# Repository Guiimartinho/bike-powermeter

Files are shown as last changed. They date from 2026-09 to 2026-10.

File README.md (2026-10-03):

<div align="center">

# Bike Power Meter

**Medidor de potência para bicicleta, aberto do extensômetro ao pod: torque por ponte de classe transdutor colada no braço do pedivela, cadência por acelerômetro, potência por BLE e ANT+. Par do [GNSS Bike Computer](https://github.com/Guiimartinho/gnss-bike-computer).**













</div>

Um módulo colado na face interna do braço esquerdo do pedivela. A ponte de extensômetros mede a **deformação do próprio braço**, que é o elemento elástico; o conversor lê a ponte em 24 bits, o acelerômetro dá o ângulo e a cadência, e o rádio publica potência, cadência e equilíbrio como qualquer medidor comercial — em **BLE Cycling Power** e **ANT+ Bicycle Power**, para o ciclocomputador do projeto ou para qualquer aplicativo.

O firmware é **obra original** em C puro sobre Zephyr, não um port. A placa, o pod e todos os desenhos são **gerados por programa** a partir dos documentos de [`hardware_powermeter/`](hardware_powermeter/README.md), pela mesma ideia do ciclocomputador: um gerador, um dry run, e nenhum número que não venha de uma ficha ou de uma medida.

> [!WARNING]
> **Nada foi fabricado, impresso, soldado nem colado, e o firmware nunca rodou.** Não existe placa física, nenhum extensômetro foi colado num pedivela, nenhum componente passou por bancada e nenhuma linha de código foi vista funcionando: tudo o que está escrito abaixo foi verificado no PC. As medidas do braço do pedivela são **lugares reservados** — ninguém mediu o braço. O estado de cada área está em [docs/07-status.md](docs/07-status.md).

## Índice

- [Visão geral](#visão-geral)
- [O aparelho](#o-aparelho)
- [Como a potência sai da deformação](#como-a-potência-sai-da-deformação)
- [Componentes](#componentes)
- [Funcionalidades](#funcionalidades)
- [Início rápido](#início-rápido)
- [Estrutura](#estrutura)
- [Documentação](#documentação)
- [Estado e próximos passos](#estado-e-próximos-passos)
- [Créditos e licença](#créditos-e-licença)

## Visão geral

```mermaid
flowchart LR
    subgraph POD["Pod colado no braço esquerdo"]
        G["Ponte S5229<br/>5 kΩ, uma peça"] -->|"2 mV"| A["ADS1220<br/>24 bits, ganho 128"]
        I["BMA400<br/>ângulo e cadência"] --> M["nRF54L15<br/>HOLYIOT-26001-A"]
        T["TMP117<br/>±0,1 °C"] --> M
        A --> M
        P["nPM1100 + célula LiPo"] --> M
        C["conector magnético<br/>carga, serial, SWD"] --> P
    end
    M -- "BLE Cycling Power" --> CC["ciclocomputador<br/>ou qualquer app"]
    M -- "ANT+ Bicycle Power" --> CC
```

## O aparelho

<div align="center">

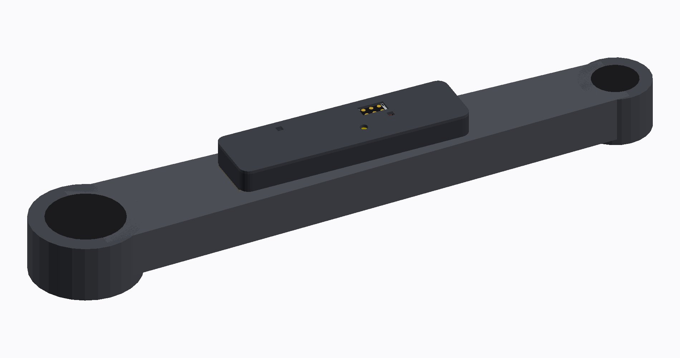
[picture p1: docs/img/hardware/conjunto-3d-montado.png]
O pod colado no braço do pedivela, visto em ângulo: a caixa preta no meio do braço, com a janela do conector magnético na tampa


*O pod no braço do pedivela. O braço é um lugar reservado, desenhado da classe (170 mm entre eixos) até o do dono ser medido; o pod, a placa e a ponte são a geometria real do projeto.*

</div>

### O produto, peça por peça

| | |
|---|---|
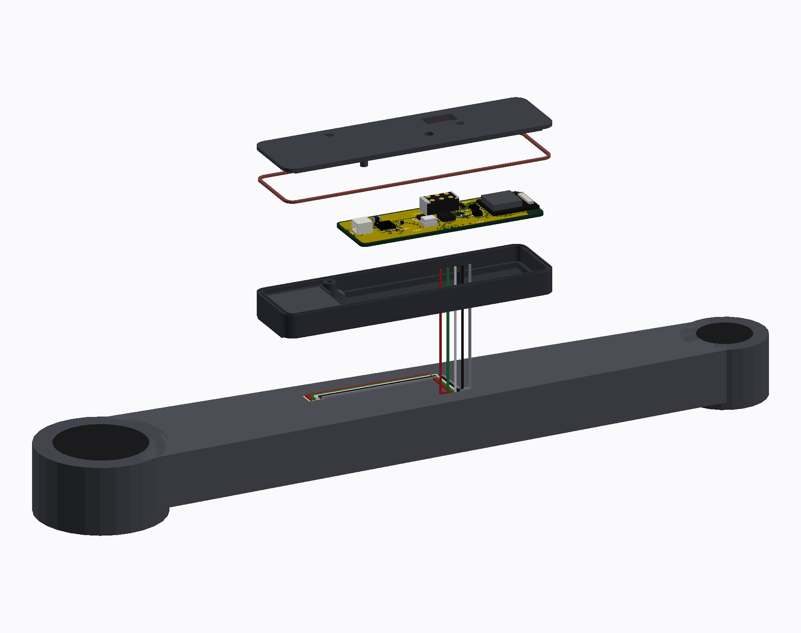
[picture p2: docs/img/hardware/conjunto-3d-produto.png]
O conjunto em vista explodida de produto: tampa, anel O, placa, célula e concha, um sobre o outro
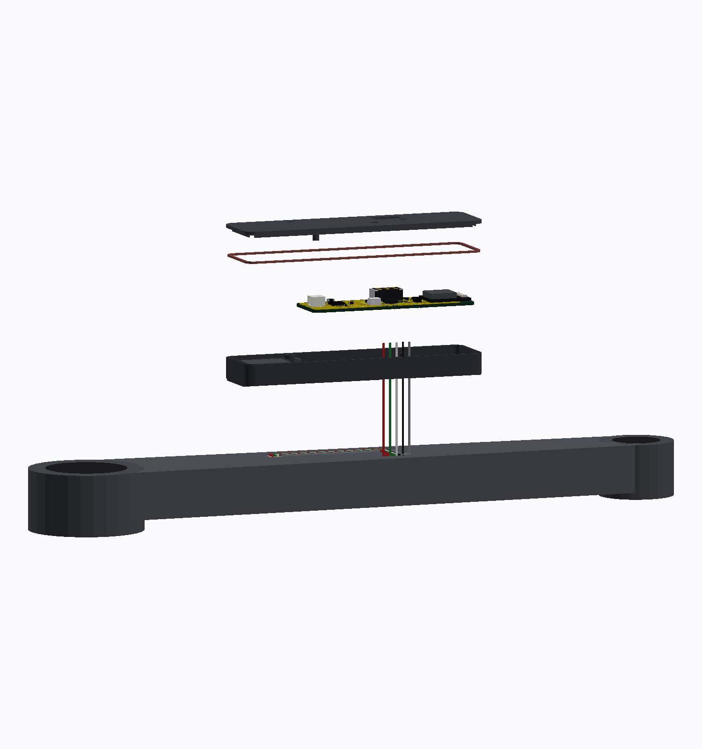
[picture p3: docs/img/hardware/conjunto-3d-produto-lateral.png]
A mesma pilha vista de lado, mostrando as alturas de cada camada
|  |  |
| *A pilha inteira: tampa, anel O, placa, célula e concha* | *De lado: 7,7 mm do fundo ao topo da tampa* |
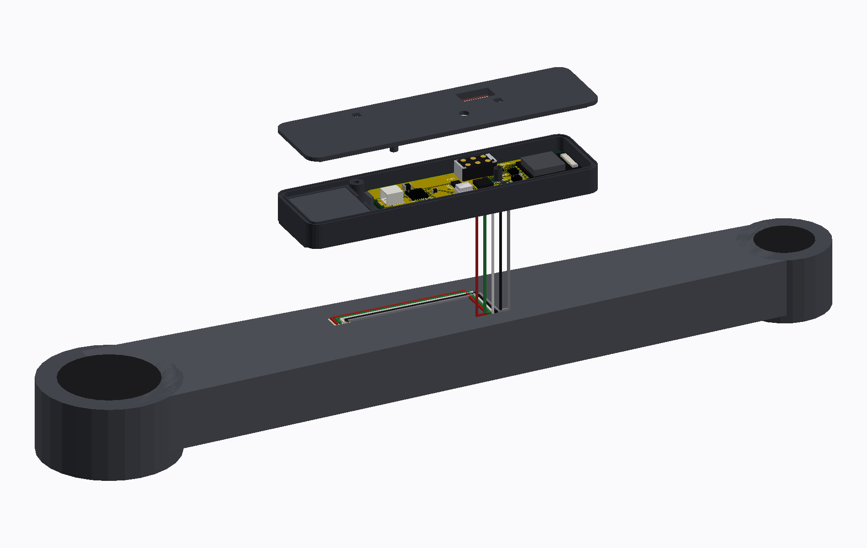
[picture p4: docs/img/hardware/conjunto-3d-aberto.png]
O conjunto em vista explodida: a tampa, o pod com a placa dentro, os cinco fios descendo e a ponte colada no braço
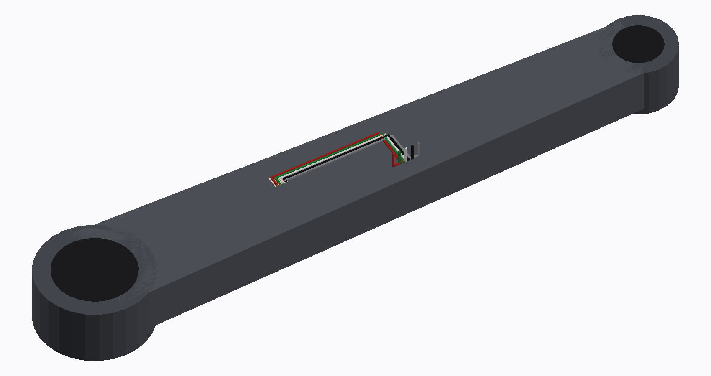
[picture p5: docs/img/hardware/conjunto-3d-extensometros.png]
Os extensômetros no braço, sob o pod
|  |  |
| *Aberto: a ponte fica no **braço**, não no pod, e cinco fios sobem por um rasgo no fundo* | *A ponte S5229 colada na face interna do braço* |

### O pod

| | |
|---|---|
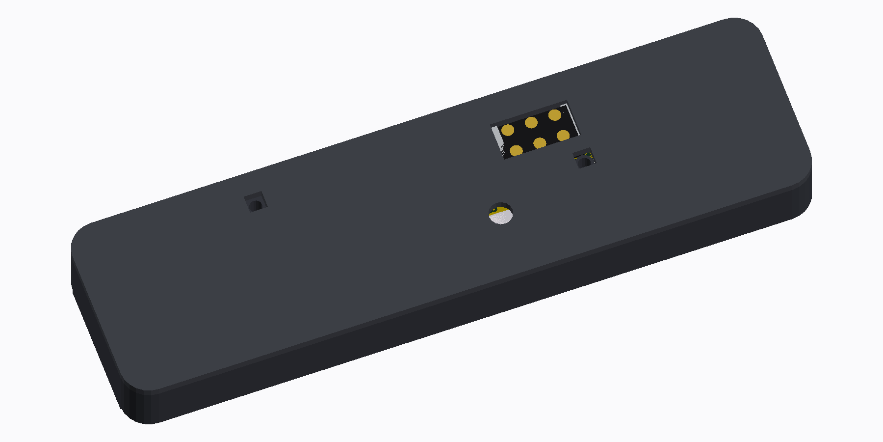
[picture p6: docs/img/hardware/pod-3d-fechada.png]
O pod fechado, visto em ângulo
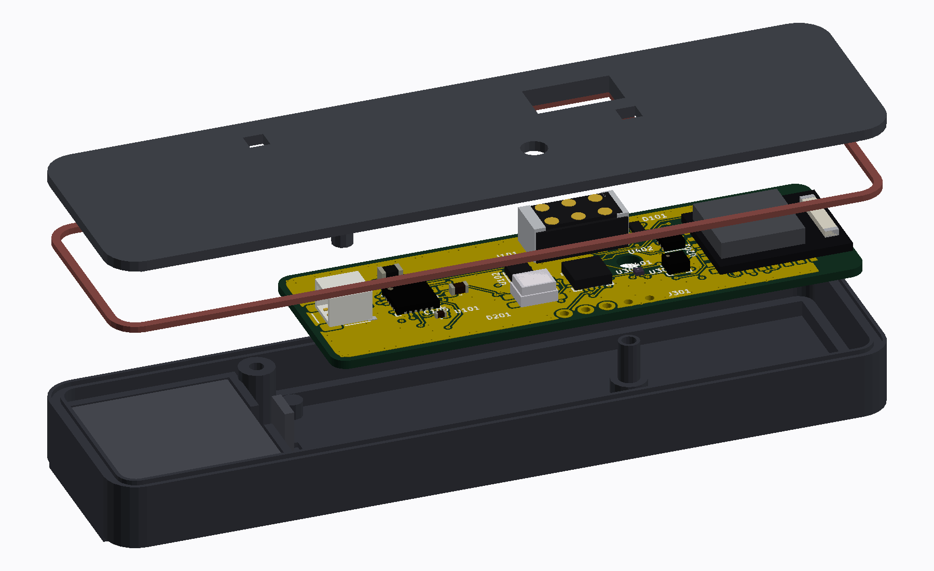
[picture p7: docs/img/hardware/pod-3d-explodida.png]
O pod em vista explodida: concha, célula, placa, anel O e tampa
|  |  |
| *Fechado: 73,5 × 20,0 × 7,7 mm, 14,3 g estimados* | *Explodido: concha, célula, placa, anel O e tampa* |
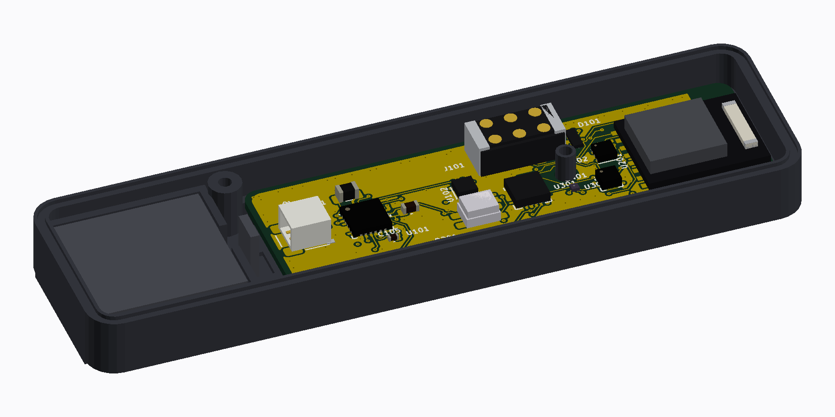
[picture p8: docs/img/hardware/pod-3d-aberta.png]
A concha aberta com a placa dentro
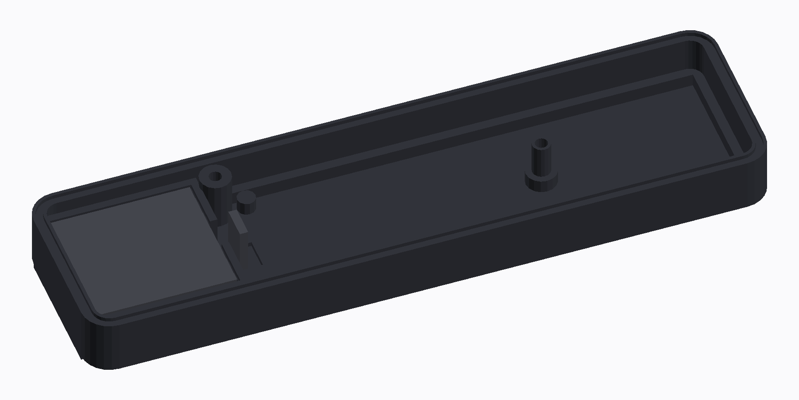
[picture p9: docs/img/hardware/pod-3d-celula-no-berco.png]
A célula no berço da concha, antes da placa
|  |  |
| *Aberto, com a placa assentada* | *A célula no berço, no passo em que ela entra* |
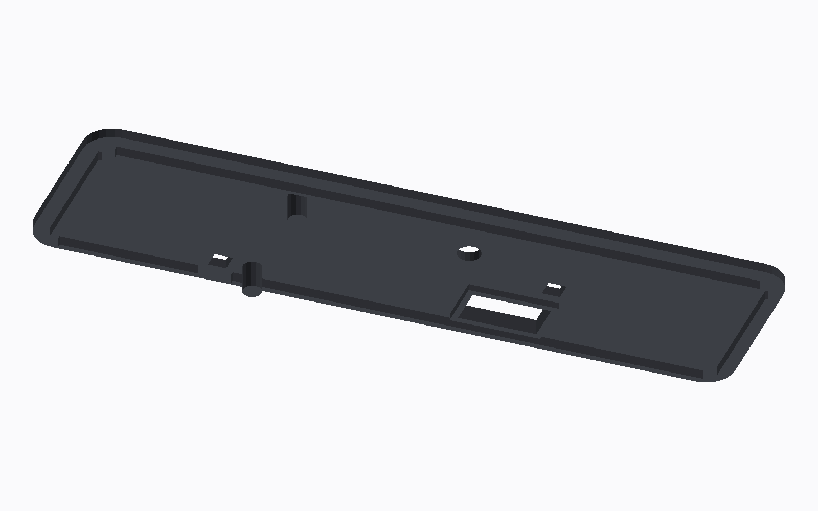
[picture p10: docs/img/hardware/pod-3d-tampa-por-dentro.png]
A tampa vista por dentro: o sulco do anel O, os dedos que prendem a placa e o ressalto que comprime a junta da porta
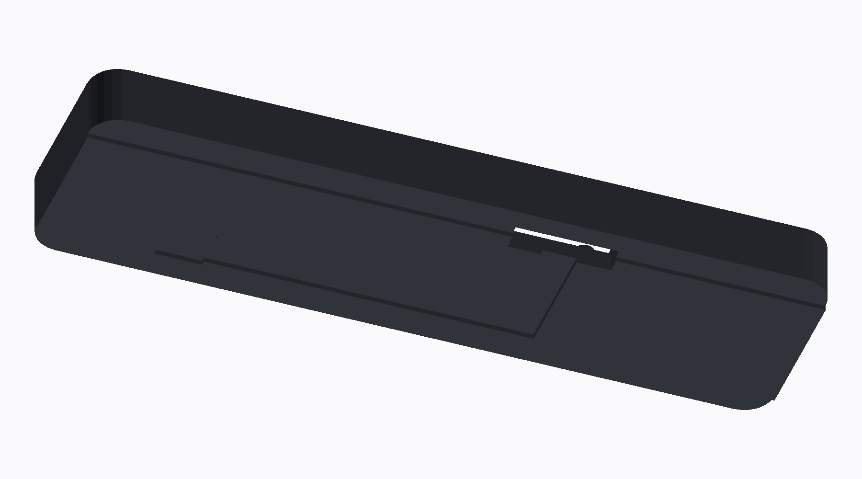
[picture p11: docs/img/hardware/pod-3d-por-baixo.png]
A concha vista por baixo: a base de colagem, o relevo, o rasgo dos fios, o bolso do extensômetro e a canaleta do feixe
|  |  |
| *A tampa por dentro: sulco do anel O, dedos da placa e o ressalto que comprime a junta da porta* | *Por baixo: a base de colagem de 14 mm, o relevo de 0,5, o rasgo dos fios, o bolso do extensômetro e a canaleta do feixe* |

### A placa

| | |
|---|---|
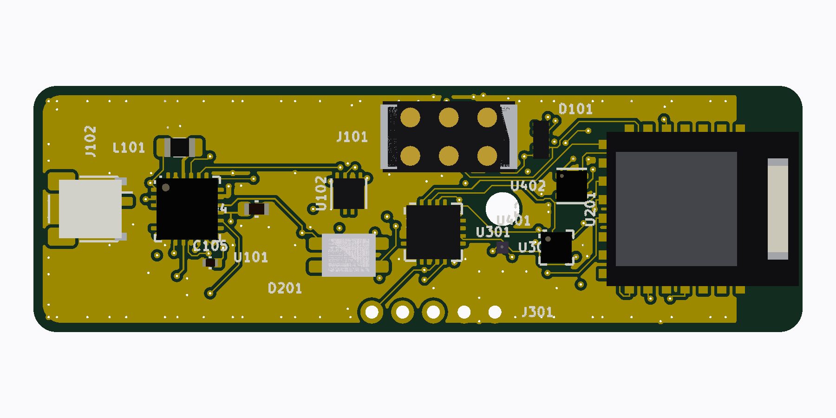
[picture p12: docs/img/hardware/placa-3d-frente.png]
A placa vista pela frente: o módulo de rádio à direita, o conector magnético na borda de cima, o conversor no meio e o conector da célula na ponta esquerda
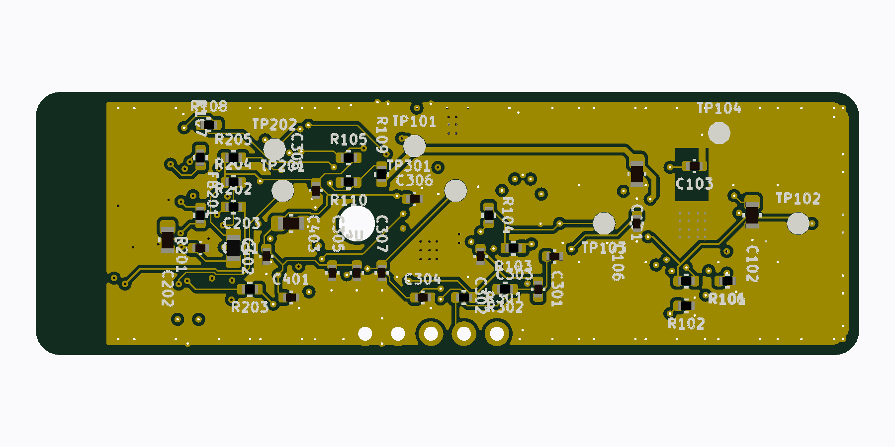
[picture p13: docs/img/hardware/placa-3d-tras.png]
A placa pelo verso: os pontos de teste e os passivos que não precisam ser alcançados
|  |  |
| *A placa, 50 × 16 mm em 4 camadas, 58 peças* | *O verso: pads de teste e o que não precisa ser alcançado, sobre o fundo rebaixado do pod* |
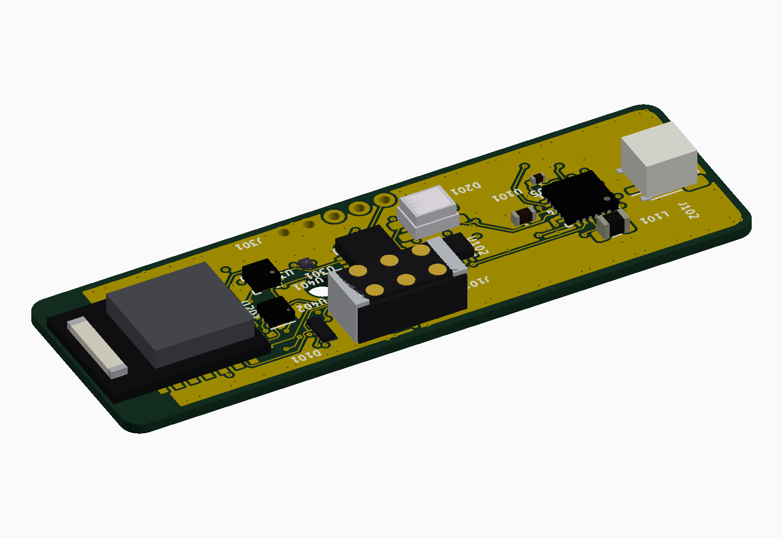
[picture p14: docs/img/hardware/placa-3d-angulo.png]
A placa vista em ângulo, com os corpos 3D de cada peça
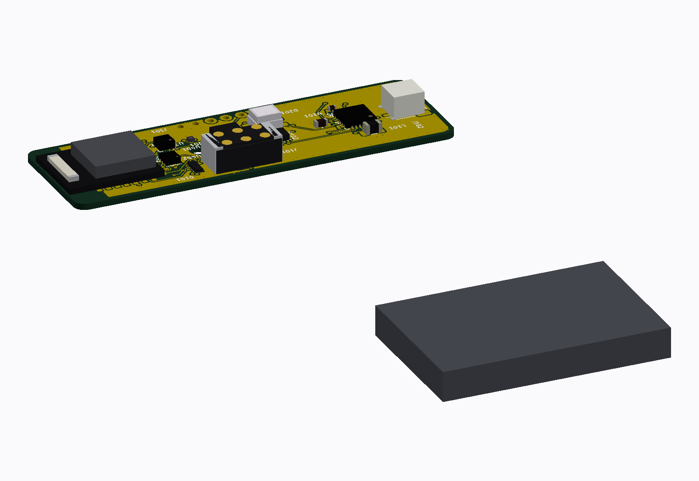
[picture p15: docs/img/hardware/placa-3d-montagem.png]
A placa com os nomes de cada peça, para a montagem
|  |  |
| *Em ângulo, com o corpo real de cada peça* | *O mapa de montagem, peça a peça* |

O envelope de referência veio de **fotogrametria** sobre as fotos de imprensa de um medidor da classe, porque nenhum fabricante publica as medidas: 37 a 39 mm de comprimento, 18 a 22 de largura e 9 a 13 de altura, com a escala aferida por dois caminhos independentes ([docs/01](docs/01-visao-geral.md)). É contra esse número que o pod é medido.

## Como a potência sai da deformação

O que quase todo texto sobre medidores esconde: **o sensor não mede força, mede o quanto o braço entorta.**

```mermaid
flowchart LR
    F["força no pedal<br/>~500 N"] --> D["o braço flexiona<br/>~571 µε na borda"]
    D --> V["a ponte desequilibra<br/>~2,28 mV"]
    V --> N["ADS1220, ganho 128<br/>24 bits ratiométrico"]
    N --> TQ["torque<br/>zero, inclinação, temperatura"]
    TQ --> PW["potência = torque × ω"]
    ANG["BMA400<br/>ângulo e ω"] --> PW
```

Duas coisas foram **medidas e corrigidas** aqui, e as duas mudam o aparelho:

- **o padrão de extensômetro especificado estava errado.** A lista pedia padrão de cisalhamento a 45°, que é padrão de torquímetro de eixo; o braço do pedivela é uma viga em balanço. Na mesma seção, a grade a 45° lê 52 µε e a grade axial na borda lê 459 µε: **8,9 vezes mais** ([docs/06](docs/06-medicao-e-calibracao.md));
- **o braço Shimano é oco.** Com parede de 3 mm o momento de inércia cai de 9.333 para 7.504 mm⁴ e a deformação sobe de 459 para **571 µε**, 24 % a mais.

A ponte é **uma peça só**, não quatro colagens: o padrão S5229 do databook de classe transdutor, `N2K-13-S5229A-50C/DG/E3`, 5 kΩ ±5 %, matriz de 4,0 × 3,7 mm, ponte de Poisson já balanceada de fábrica. O código `13` é a autocompensação para alumínio; **sem ele escrito no pedido o fabricante embarca o `06`, que é o de aço**.

## Componentes

| Bloco | Peça | Por quê |
|---|---|---|
| Ponte | Micro-Measurements `N2K-13-S5229A-50C/DG/E3` | ponte completa numa colagem só, 5 kΩ (0,6 mA em vez de 3,0), balanceada de fábrica, autocompensada para alumínio |
| Conversor | TI ADS1220 | 0,26 µV RMS com ganho 128, 585 µA medindo, referência **ratiométrica** (a excitação é a referência, então a tensão da célula sai da conta) |
| Cadência e ângulo | Bosch BMA400 | 850 nA a 25 Hz; driver próprio, porque o `bosch,bma4xx` da árvore usa o mapa do BMA422 |
| Temperatura | TI TMP117 | ±0,1 °C para o ajuste do zero e da inclinação |
| MCU e rádio | **HOLYIOT-26001-A** (nRF54L15), antena cerâmica | 10,0 × 12,5 mm contra 16,5 × 12,0 do ME54BS13: o módulo era **26 % da área da placa**, mais que as 37 peças pequenas somadas, e é a única alavanca de tamanho que move alguma coisa. Custa o USB, que este SoC não tem ([09](hardware_powermeter/09-modulo-de-radio.md)) |
| Carga e 3,0 V | Nordic nPM1100 | carregador e buck numa peça, 800 nA |
| Excitação | TI TPS22916 | desliga a ponte entre amostras; é ela que faz os 5 kΩ valerem a pena |
| Bateria | LiPo de bolsa classe **`401123`** (4,0 × 11 × 23 mm, ≥ 78 mAh, dois fios, proteção integrada) | a 0,68 mA — ponte de 5 kΩ com o conversor em duty-cycle — são **114 h**, contra as 50 h do requisito. A premissa anterior, de 2,5 mm de espessura, não existe: naquele volume a célula vale ~49 mAh. Nenhuma loja foi alcançada: o envelope é **requisito de compra** |
| Conector | magnético de 6 contatos, **desenhado aqui** | carga, serial e SWD num cabo só, sem tampa de borracha para perder. Contatos chatos de ouro no aparelho e molas no cabo, para o pod poder ser vedado ([06](hardware_powermeter/06-conectores-e-pontos-de-teste.md#j101--conector-magnético)) |

Lista completa, com a ficha e o código de compra de cada peça: [`hardware_powermeter/01-lista-de-componentes.md`](hardware_powermeter/01-lista-de-componentes.md).

## Funcionalidades

| Funcionalidade | Estado |
|---|---|
| Torque por ponte, com zero, inclinação e ajuste de temperatura | modelo escrito e testado no PC (18 casos, 50 de 50 linhas) |
| Ângulo e cadência pelos cruzamentos de zero do eixo tangencial | modelo escrito e testado (18 casos, 113 de 113 linhas) |
| Potência, equilíbrio e eficiência por volta | modelo escrito e testado (12 casos, 80 de 80 linhas) |
| Calibração: zero, inclinação por mínimos quadrados, massa conhecida | modelo escrito e testado (18 casos, 135 de 135 linhas) |
| BLE Cycling Power (Measurement, Feature, Control Point, Vector) | compila; os bytes vêm do modelo testado; nunca visto por um cliente |
| Serviço de configuração por BLE, com **escrita cifrada obrigatória** | compila; nunca emparelhado |
| ANT+ Bicycle Power (páginas 1, 16, 18, 80, 81) | compila com `ANT=1`; nenhum canal aberto de verdade |
| Atualização por BLE (mcumgr + MCUboot) e recuperação serial pela **UART** do conector magnético | compila; recusa pedalando ou com bateria fraca |
| Placa e pod gerados por programa, com dry run | placa colocada; pod fecha **16 de 16** regras, com vedação por anel O, parafusos, retenção e dreno |

## Início rápido

**Pré-requisitos** (Windows): nRF Connect SDK v3.3.0 em `C:\ncs` com o toolchain `936afb6332`, SEGGER J-Link e um nRF54LM20 DK. Para o ANT, o add-on `sdk-ant` em `C:\ncs\sdk-ant`, depois de aceitar o acordo ANT+. Para os testes de host, MinGW-w64 GCC, CMake e Ninja. Para o CAD, KiCad 8 em `D:\KiCAD`. Detalhes em [docs/03-ambiente-build.md](docs/03-ambiente-build.md).

```sh
# Git Bash, na raiz do repositório
bash tools/fw/fw.sh build            # compila para o nRF54LM20 DK (sysbuild + MCUboot)
BOARD=pmboard/nrf54l15/cpuapp BUILD_DIR=zephyr_app/build_custom bash tools/fw/fw.sh build
ANT=1 BUILD_DIR=zephyr_app/build_ant bash tools/fw/fw.sh build   # com a pilha ANT+
bash tools/fw/host_tests.sh          # 9 conjuntos, 134 casos
bash tools/fw/host_tests.sh coverage # e falha abaixo de 95 % em qualquer módulo
python tools/fw/board_check.py       # confere o devicetree contra o silício, docs/02 e o esquemático
python tools/docs/mermaid_check.py   # valida os diagramas da documentação
python tools/verificar_tudo.py       # a verificação inteira, três vezes
```

A cadeia de CAD, com o intérprete certo de cada etapa (o `fill_zones.py` **só** roda com o Python do KiCad), está em [`hardware_powermeter/cad/README.md`](hardware_powermeter/cad/README.md#a-cadeia).

O CI está **desligado**: a verificação é local.

## Estrutura

```mermaid
flowchart TB
    ROOT["bike_powermeter/"]
    ROOT --> ZA["zephyr_app/<br/>src (app · svc · model · rf) · include<br/>modules/pm_drivers (ADS1220, BMA400)<br/>boards · tests/host"]
    ROOT --> HW["hardware_powermeter/<br/>01 a 10 · cad (KiCad e geradores)<br/>esquematico · placa · pod (gerador, dry run, STL)<br/>datasheets (fora do git)"]
    ROOT --> DOCS["docs/<br/>01 a 07 · img/hardware (15 vistas)"]
    ROOT --> TOOLS["tools/<br/>fw · docs · verificar_tudo.py"]
    ROOT --> AI["CLAUDE.md · AGENTS.md · .claude/skills/"]
```

## Documentação

| Documento | Assunto |
|---|---|
| [01 · Visão geral](docs/01-visao-geral.md) | o que é, o envelope da classe por fotogrametria, as fases |
| [02 · Hardware](docs/02-hardware.md) | blocos da placa, pinos do módulo, orçamento de consumo, pod |
| [03 · Ambiente e build](docs/03-ambiente-build.md) | NCS v3.3.0, os três alvos, scripts, gravação |
| [04 · Arquitetura do firmware](docs/04-arquitetura-firmware.md) | os seis serviços, threads, pilhas, máquinas de estado |
| [05 · Protocolos](docs/05-protocolos.md) | BLE Cycling Power, ANT+ Bicycle Power, serviço de configuração com os UUID |
| [06 · Medição e calibração](docs/06-medicao-e-calibracao.md) | da deformação ao torque, flexão × cisalhamento, zero, inclinação, temperatura, saúde |
| [07 · Status](docs/07-status.md) | o que existe, o que foi verificado e como, o que falta |
| [Hardware](hardware_powermeter/README.md) | o esquemático, a placa, o pod, os dry runs e o que falta antes de fabricar |
| [CAD](hardware_powermeter/cad/README.md) | os geradores, as regras e as armadilhas medidas |
| [Pod](hardware_powermeter/pod/README.md) | o gerador do invólucro, as 32 regras do dry run e o que é decisão do desenho |
| [Módulo de rádio](hardware_powermeter/09-modulo-de-radio.md) | o HOLYIOT-26001-A: por que entrou, o que o nRF54L15 muda, pinagem, mecânica, a antena |
| [A classe medida](hardware_powermeter/12-comparacao-com-a-classe.md) | o 4iiii Precision 3+ e o U2e V4 contra o nosso, e o que custaria chegar ao alvo de envelope |
| [CHANGELOG](CHANGELOG.md) | histórico de mudanças |

## Estado e próximos passos

- **Feito em 2026-09-27:** a documentação de requisitos, arquitetura, protocolos e método de medição com as referências; a lista de componentes fechada por ficha; os nove módulos do modelo escritos e testados no PC (134 casos, 100 % das linhas, doze mutações mortas); o firmware embarcado inteiro compilando com **zero avisos** nos três alvos; o esquemático, a placa e o pod gerados por programa com os dois dry runs.
- **Feito em 2026-09-28:** a ponte fechada numa peça só (S5229 de 5 kΩ) com a designação de compra dos braços do dono; a correção do padrão de extensômetro (flexão, não cisalhamento: 8,9 vezes mais sinal); o roteador passou a ser julgado pelo **DRC do KiCad** em vez da própria contabilidade; três defeitos mecânicos do pod medidos e corrigidos, e o dry run fechou **12 de 12**.
- **Falta antes de fabricar:** fechar o roteamento, medir o pedivela do dono (quatro números), escolher a célula, fechar o conector magnético e conferir o empilhamento com o fabricante. A lista está em [`hardware_powermeter/README.md`](hardware_powermeter/README.md#antes-de-mandar-fabricar).
- **Depois:** bancada com massas de 5 a 20 kg contra o braço instrumentado, prova de estrada contra um medidor de referência até ±2 %, e a fase 2 no eixo de pedal.

## Créditos e licença

Projeto de Luiz Guilherme Ito. As referências técnicas — notas de aplicação dos fabricantes, databooks de extensometria, normas e artigos — estão citadas nos documentos que as usam, principalmente em [`docs/06-medicao-e-calibracao.md`](docs/06-medicao-e-calibracao.md) e [`hardware_powermeter/01-lista-de-componentes.md`](hardware_powermeter/01-lista-de-componentes.md).

Licença **CC BY-NC 4.0** ([`LICENSE`](LICENSE)), a mesma do GNSS Bike Computer: copiar, estudar, modificar e redistribuir com atribuição, **sem uso comercial**. Não é licença aprovada pela Open Source Initiative, que não admite restrição de uso, e foi escolhida por isso. O firmware deste projeto é obra original, não um port.

O material do ANT+ — perfis de dispositivo, código sob a ANT+ Shared Source License, chave de rede — **nunca entra neste repositório**: o ANT+ Adopter Agreement proíbe redistribuir. O que existe aqui é código próprio chamando a API do add-on. As fichas dos fabricantes ficam fora do git.

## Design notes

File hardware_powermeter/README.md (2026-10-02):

# Hardware do medidor de potência

O aparelho inteiro em CAD: o esquemático, a placa de quatro camadas, o pod
impresso em volta dela e as medidas que cada um tem de passar. Tudo é
**gerado por programa** a partir dos documentos desta pasta, pela mesma
ideia do ciclocomputador: um gerador, um dry run, e nenhum número que não
venha de uma ficha ou de uma medida.

> [!WARNING]
> **Nada foi fabricado, impresso, soldado nem colado.** Não existe gerber
> enviado, não existe placa física, nenhuma peça passou por bancada e
> nenhum extensômetro foi colado num pedivela. O que existe é o projeto em
> KiCad, os STL do pod e os dry runs que os medem. As medidas do braço do
> pedivela são **lugares reservados**: ninguém mediu o braço do dono.

## Índice

- [O que existe](#o-que-existe)
- [A cadeia](#a-cadeia)
- [Os documentos](#os-documentos)
- [Os dry runs](#os-dry-runs)
- [Antes de mandar fabricar](#antes-de-mandar-fabricar)

## O que existe

| Parte | Estado |
|---|---|
| Esquemático | 4 folhas, 58 peças, 43 nós, gerado e conferido nó a nó contra `nets.py` pelo `check_sch.py` |
| Placa | **50 × 16 mm**, 4 camadas, 58 peças mais um furo de fixação M1,6, 43 redes; **roteada por inteiro** — 838 trilhas, 221 vias, 0 erros de DRC e 0 ligações em aberto |
| Pod | **73,5 × 20,0 × 7,7 mm**, 14,5 g estimados, com a célula **ao lado** da placa, vedado por anel O e por uma junta no ombro do conector, fechado por dois parafusos M1,6, dois STL (concha e tampa) |
| Ponte | S5229 de 5 kΩ numa peça só, `N2K-13-S5229A-50C/DG/E3`, colada no braço |

## A cadeia

```mermaid
flowchart LR
    SCH["make_sch.py"] --> CSCH["check_sch.py"]
    CSCH --> PDFS["esquematico/pmeter-esquematico.pdf"]
    DXF["make_dxf.py"] --> CDXF["check_dxf.py"]
    CDXF --> PCB["make_pcb.py"]
    PCB --> ROUTE["route.py + route_neg.py"]
    ROUTE --> FILL["fill_zones.py"]
    FILL --> DRC["kicad-cli pcb drc"]
    DRC --> REP["reparar.py"]
    REP --> DRY["dry_run_pcb.py"]
    DRY --> V3D["make_3d.py · make_2d.py · montagem.py"]
    V3D --> POD["pod/dry_run_pod.py · pod/make_pod.py"]
    POD --> CONJ["pod/make_conjunto.py"]
```

Os comandos, um a um, com o intérprete certo de cada etapa, estão em
[`cad/README.md`](cad/README.md#a-cadeia). Duas armadilhas que custam caro:
o `fill_zones.py` **só** roda com o Python do KiCad, e o `check_pcb.py`
regera a placa se você esquecer o `--como-esta`.

## Os documentos

| Documento | Assunto |
|---|---|
| [01 · Lista de componentes](01-lista-de-componentes.md) | cada peça com o número da ficha, incluindo a ponte S5229 e as armadilhas de compra |
| [02 · Esquemático](02-esquematico.md) | as quatro folhas, bloco a bloco |
| [03 · Netlist](03-netlist.md) | os 43 nós, pino a pino, e os pinos deixados abertos de propósito |
| [04 · Placa](04-placa.md) | contorno, camadas, posicionamento, zonas proibidas, land pattern do módulo, roteamento |
| [05 · Materiais](05-materiais.md) | a lista de montagem com footprint e código de compra |
| [06 · Conectores e pontos de teste](06-conectores-e-pontos-de-teste.md) | o conector magnético, os furos da ponte, os furos da célula, o Tag-Connect |
| [07 · Pod](07-pod.md) | o invólucro: envelope, pilha de alturas, o que segura cada peça, vedação, massa |
| [08 · Dry run de 2026-09-27](08-dry-run-2026-09-27.md) | a primeira medida completa da placa e do pod |
| [09 · Módulo de rádio](09-modulo-de-radio.md) | o HOLYIOT-26001-A: por que ele entrou, o que o nRF54L15 muda, pinagem, mecânica, a antena |
| [10 · Dry run de 2026-09-28](10-dry-run-2026-09-28.md) | a medida completa depois da troca do módulo, da célula real e da vedação |
| [11 · Revisão de 2026-10-01](pod/11-revisao-2026-10-01.md) | dez revisores sobre o pod: sete bloqueantes, e por que o dry run não os via |
| [12 · A classe medida](12-comparacao-com-a-classe.md) | o 4iiii Precision 3+ e o U2e V4 contra o nosso, pelo que publicam; o que custaria chegar ao alvo de envelope; Apple Find My e Samsung Find |
| [CAD](cad/README.md) | os geradores, o que muda em relação ao ciclocomputador, as regras e as armadilhas |

## Os dry runs

Duas ferramentas, e as duas **falham dizendo que não puderam medir** quando
não acham o que medir — foi assim que se descobriu que a `ME2` do
ciclocomputador passou dias sem sombra nenhuma para medir.

| Ferramenta | O que mede |
|---|---|
| [`cad/dry_run_pcb.py`](cad/dry_run_pcb.py) | as regras que as fichas dos componentes e a IPC-2221B impõem à placa: isolamento da antena, laço de chaveamento, desacoplamento junto do pino, orientação do acelerômetro, corpos 3D contra o footprint |
| [`pod/dry_run_pod.py`](pod/dry_run_pod.py) | o pod contra a placa real: a placa na cavidade, o teto da tampa, a janela do conector, o ar sob cada peça do verso, a célula, o rasgo dos fios, os pilares, o envelope e a massa |

O dry run do pod lê a placa colocada, então roda **depois** do `make_pcb.py`;
o `make_conjunto.py`, que desenha o pod no braço do pedivela com a ponte
colada, roda depois dos dois.

## Antes de mandar fabricar

Nada disto foi feito, e nenhum arquivo de fabricação deve sair antes:

1. **Fechar o roteamento.** O número atual está em
   [04](04-placa.md#roteamento) e a placa **não é fabricável** enquanto
   houver ligação sem cobre.
2. **Medir o pedivela do dono** (Shimano 105 e Ultegra): largura da face
   interna, folga até o quadro, raio da concordância e distância do eixo ao
   pod. São quatro números e hoje são lugares reservados
   ([07](07-pod.md#lugares-reservados)).
3. **Escolher a célula** dentro do envelope de 23 × 13 × 2,5 mm e conferir a
   capacidade contra as 50 h de [`docs/02`](../docs/02-hardware.md#orçamento-de-consumo).
4. **Fechar o conector magnético**: a peça de hoje é genérica
   (`confirmed=False` em `cad/parts.py`), e trocá-la troca o footprint, a
   altura e a janela da tampa.
5. **Pedir a ponte com o código de autocompensação escrito**: sem ele o
   fabricante embarca o `06`, que é o de aço, e o braço do dono é de
   alumínio ([01](01-lista-de-componentes.md)).
6. **Conferir o empilhamento com o fabricante**: as quatro camadas aqui são
   assimétricas e a impedância do par USB foi calculada para 0,10 mm de
   dielétrico sob a `F.Cu`.

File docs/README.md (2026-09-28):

# Documentação

| Documento | Assunto |
|---|---|
| [01-visao-geral.md](01-visao-geral.md) | o que é o medidor, decisão de arquitetura, estado |
| [02-hardware.md](02-hardware.md) | blocos da placa, consumo, pod |
| [03-ambiente-build.md](03-ambiente-build.md) | ambiente, build, gravação |
| [04-arquitetura-firmware.md](04-arquitetura-firmware.md) | serviços, threads, máquinas de estado |
| [05-protocolos.md](05-protocolos.md) | BLE Cycling Power, ANT+ Bicycle Power, serviço de configuração |
| [06-medicao-e-calibracao.md](06-medicao-e-calibracao.md) | ponte, amostragem, zero, inclinação, temperatura |
| [07-status.md](07-status.md) | o que existe, o que falta |

O hardware tem índice próprio em [`../hardware_powermeter/README.md`](../hardware_powermeter/README.md): a lista de componentes, o esquemático, a placa, o pod, o módulo de rádio e os relatórios de dry run.

As imagens ficam em [`img/hardware/`](img/hardware): quinze vistas do produto, do pod e da placa, todas geradas por `hardware_powermeter/cad/make_3d.py`, `pod/make_pod.py` e `pod/make_conjunto.py`.

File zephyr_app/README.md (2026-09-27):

# Firmware

Zephyr / nRF Connect SDK v3.3.0, mesma base do ciclocomputador: serviços com thread e caixa de entrada, eventos no zbus, máquinas no SMF, watchdog por serviço. Alvo: módulo MinewSemi ME54BS13 (nRF54LM20A); desenvolvimento no nRF54LM20 DK.

| Pasta | Conteúdo |
|---|---|
| `src/app`, `include/app` | inicialização, watchdog, configuração |
| `src/svc` | serviços: amostragem da ponte, cadência (IMU), cálculo por volta, rádio (BLE CPS e ANT+ BPWR), energia, USB |
| `src/model` | torque, potência, calibração e compensação de temperatura (lógica pura, testada no PC) |
| `src/rf` | servidor BLE Cycling Power, serviço de configuração do projeto, perfil ANT+ (fora do repositório) |
| `modules/pm_drivers` | drivers próprios: ADS1220 (o Zephyr não o traz) |
| `tests/host` | Unity + CTest, shims do Zephyr |
| `boards` | overlays do DK e a placa própria |

Ainda não há código: a estrutura foi criada em 2026-09-27.

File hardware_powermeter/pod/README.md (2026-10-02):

# Pod

O invólucro do módulo, colado na face interna do braço esquerdo do
pedivela. É desenhado **em volta da placa real** (`cad/pmeter.kicad_pcb`,
lida com o contorno de ocupação, a altura e a face de cada peça) e da
célula, pela mesma ideia do case do ciclocomputador: um gerador e um dry
run próprio. O que ele é e o que decide está em [07-pod.md](../07-pod.md).

**73,5 × 20,0 × 7,7 mm, 14,5 g estimados.** Nada foi impresso nem montado.

| Arquivo | O que faz |
|---|---|
| `make_pod.py` | desenha o pod: concha e tampa em STL, `pmeter-pod.pdf` com planta, cortes e a página das decisões, e **seis vistas** em `docs/img/hardware/`: `pod-3d-aberta`, `pod-3d-fechada`, `pod-3d-explodida`, `pod-3d-tampa-por-dentro`, `pod-3d-celula-no-berco` e `pod-3d-por-baixo` |
| `dry_run_pod.py` | mede o pod contra a placa: **32 regras** (`PD1` a `PD32`), cada uma com a fonte, e **uma regra que não acha o que medir falha dizendo isso** |
| `medir.py` | rasteriza em voxels as primitivas que a `Malha` registrou ao desenhar, e lê as arestas dos STL: é o que permite medir o sólido em vez da constante |
| `regras_medidas.py` | as doze regras que medem o sólido (`PD21` a `PD32`) |
| `make_conjunto.py` | o pod no braço do pedivela: `conjunto-3d-montado`, `conjunto-3d-aberto`, `conjunto-3d-extensometros`, `conjunto-3d-produto` e `conjunto-3d-produto-lateral` |
| `pod-concha.stl`, `pod-tampa.stl` | união de sólidos fechados para o fatiador, não sólido de CAD |
| `pmeter-pod.pdf` | 3 páginas: planta, cortes, decisões e lugares reservados |
| `11-revisao-2026-10-01.md` | a revisão de dez revisores que motivou o desenho de hoje |

## Ordem

```mermaid
flowchart LR
    PCB["cad/make_pcb.py → route.py<br/>→ fill_zones.py → dry_run_pcb.py"] --> GLB["cad/make_3d.py<br/>exporta o GLB"]
    GLB --> POD["pod/make_pod.py<br/>PDF, STL, 6 vistas"]
    PCB --> DRY["pod/dry_run_pod.py<br/>32 regras"]
    POD --> CONJ["pod/make_conjunto.py<br/>o pod no pedivela"]
    POD --> DRY
```

`dry_run_pod.py` lê a placa colocada (roda logo depois do `make_pcb.py`) e,
desde 2026-10-01, também os **STL**, que `make_pod.py` grava: rode o gerador
antes dele. `make_pod.py` precisa do GLB, que o `dry_run_pcb.py` e o
`make_3d.py` exportam — e o `make_3d.py` **o reexporta sozinho** quando ele
está mais velho que a placa, para os corpos de agora nunca aparecerem sobre a
placa de antes. Os três rodam com o Python do sistema, da raiz do repositório:

```
python hardware_powermeter/pod/make_pod.py
python hardware_powermeter/pod/dry_run_pod.py
python hardware_powermeter/pod/make_conjunto.py
```

## Medir o sólido, não a constante

Em 2026-10-01 dez revisores mediram este pod e acharam sete interferências
que o impediam de fechar. No mesmo commit, o dry run dizia que **18 das 20
regras estavam cumpridas**. A causa era uma só: o desenho é uma sopa de
triângulos, a classe `Malha` não sabia subtrair e não dava para perguntar a
ela "este ponto está dentro?", então sete regras liam a **constante** que
deveria ter gerado a geometria. Uma regra assim passa com a peça desenhada
ou sem ela — `PARAF_PESCOCO_D = 2,00` estava declarado desde sempre, o
ressalto saía em diâmetro cheio de 3,40 por um furo de 2,20, e nenhuma regra
viu.

O que mudou:

```mermaid
flowchart TB
    DES["make_pod.Malha<br/>desenha triângulos"] --> REG["Malha.solidos e Malha.faixas<br/>registram cada primitiva<br/>na MESMA chamada"]
    REG --> VOX["medir.Grade<br/>rasteriza em voxels de 0,1 mm"]
    VOX --> R21["PD21 interferência entre corpos"]
    VOX --> R22["PD22 caminho contínuo do fio"]
    VOX --> R23["PD23 face de baixo ponto a ponto"]
    VOX --> R24["PD24 aperto da junta da porta"]
    VOX --> R25["PD25 fio dentro da linha de cola"]
    REG --> R26["PD26 toda primitiva fecha"]
```

Como o registro é feito pela mesma chamada que emite os triângulos, ele não
pode divergir da malha. Cada regra nova foi **testada por mutação**: o
defeito volta ao gerador e a regra tem de reprovar.

| Regra | Reprova quando | Mutação conferida em 2026-10-01 |
|---|---|---|
| `PD21` | dois corpos ocupam o mesmo espaço | aba fechada: 2 pares, 2,97 mm³ |
| `PD22` | o fio da célula não tem caminho contínuo | corte da passagem removido: "não passa fio de 0,90" |
| `PD23` | a face de baixo toca fora da base de colagem | relevo acrescentado em vez de cavado: 302,7 mm² |
| `PD24` | a junta da porta não é comprimida | ressalto removido: "comprimida 0,0 %" |
| `PD25` | fio ou matriz dentro da linha de cola | canaleta de 0,2: 96,7 mm² sem cola; canaleta nenhuma: "não mede nada" |
| `PD14` | o que atravessa a placa não cabe no furo | pescoço em diâmetro cheio: 3,40 contra 2,20; sem pescoço: "não há sólido nenhum" |
| `PD9` | o furo de luz não é redondo | furo quadrado: 6,25 mm² contra 4,91 |
| `PD27` | uma constante de geometria não é usada | constante nova sem uso: pega pelo nome |
| `PD31` | a anilha não veda a cabeça | anilha de 3,0 sob cabeça de 3,2: "ela não veda" |

## O que é decisão deste desenho

Tudo em `make_pod.py`, em constantes com o motivo ao lado.

| O quê | Valor | Por quê |
|---|---|---|
| Paredes | **1,50 mm**, derivadas da vedação | a parede **sai** do selo: sulco de 0,78 mais 0,36 de terra de cada lado. Eram 2,0, escritas como número solto ao lado de um sulco também solto, e isso manteve a parede grande depois que o cordão já podia ser menor. Com cordão de 0,60 a largura do pod vai a **20,0 exatos** ([12](../12-comparacao-com-a-classe.md#o-item-2-feito-a-parede-sai-da-vedação)) |
| Fundo | **1,2 mm**, tampa 1,0, raio 3 | o fundo subiu de 1,0 em 2026-10-01: fora da base de colagem a face de baixo está em `RELEVO`, e com 1,0 o piso ali daria 0,5 mm |
| Célula | **15 × 14 × 5,0 mm**, **ao lado** da placa, em baía **cavada no piso** | ≥ 81 mAh (1.050 mm³ a 0,077 mAh/mm³). Decisão do dono em 2026-09-30: ao lado, a célula sai da pilha. A baía é cavada 0,5 mm para a reserva de inchaço não levantar o teto da cavidade |
| Reserva de inchaço | **0,5 mm** (10 % da espessura) | uma bolsa de lítio engorda com ciclo e temperatura; era 0,000 mm, com igualdade exata, enquanto a `PD2` cobrava 0,30 de toda peça rígida |
| Passagem dos fios | **3,4 mm** cortados nas nervuras e no piso | `CELULA_FIO_PASSO + CELULA_FIO_D`; até 2026-10-01 as nervuras iam do piso ao teto e a saída real era **0,000 mm**. Por ela passam os dois fios **e o plugue**, e a `PD32` mede o curso de encaixe |
| Conector da célula | **JST SH `SM02B-SRSS-TB`**, entrada lateral, 2,90 mm | a célula entra por conector, não por fio soldado (decisão do dono em 2026-10-01). A série é requisito de compra: com PH de 2,0 o pod iria a 9,7 mm e o conector magnético teria de mudar |
| Vedação da caixa | anel O de cordão **0,60 mm** em sulco de 0,78 × 0,45 | **23,3 % de compressão medidos no sólido**, dentro da faixa de 20 a 30 %. O cordão de 0,60 é requisito de compra |
| Vedação da porta | junta plana de **0,65 mm** no **ombro do conector**, comprimida 0,20 de 0,70 (28,6 %) por um ressalto da tampa | `docs/02`: "junta na face do conector". O lábio e o dreno saíram: o lábio ficava 0,40 acima da junta e o dreno 0,50 **acima** do fundo do poço |
| Fechamento | **dois parafusos M1,6** autoatarraxantes, ressalto de 3,40, furo-guia de 1,35, cabeça **cilíndrica saliente sobre anilha vedante** de 4,0 comprimida 30 % | um deles passa **pelo furo da placa** por um pescoço de 2,00, que segue acima dela até passar o nível do envase. O tampão de resina sobre cabeça escareada não cabia: 0,96 de cabeça mais 0,80 de tampão contra 1,00 de tampa, e um escareado de 3,20 não entra num furo de 1,90 |
| Assento da placa | **0,5 mm** por borda (`RESSALTO = FOLGA_PLACA + ASSENTO_MIN`) | eram 0,100 mm, a mesma medida da folga radial do pino: a placa saía do ressalto só deslizando |
| Teto sobre a placa | **3,2 mm** | `cad/make_dxf.TETO_TAMPA`, que desde 2026-10-01 **sai** da altura do conector da célula (`footprints.CONECTOR_CELULA`): o JST SH tem 2,90 mais 0,3 de ar, e é ele a peça mais alta sob a tampa |
| Base de colagem | **14 mm** de largura, com relevo de **0,5 mm** cavado em volta | a face do braço só é plana em 15 dos 20 mm, e a base guarda 0,5 de margem por lado. O relevo era **acrescentado** onde queria cavar: 100 % das tiras externas era face maciça em z = 0 |
| Bolso e canaleta | sobre a matriz do extensômetro e sobre o feixe dos cinco fios | na linha de cola de 0,5 não cabe nem o fio (0,5 com isolação) nem a matriz; o maior percurso media **44,83 mm sob fundo colado** |
| Nível do envase | **0,4 mm abaixo do teto** | não existia número nenhum: o menisco ficava rasante à boca dos furos cegos dos parafusos, e um M1,6 autoatarraxante não atarraxa em resina curada |
| Rasgo dos fios | no fundo, sob os cinco furos da ponte, com colar de altura **por barra** | cada barra para 0,1 mm abaixo do que passa sobre ela; a barra y+ esmagava o R302 e o C304 |
| Furo de luz | 2,5 mm sobre o LED | |

As medidas do braço são **lugares reservados** até serem medidas no
pedivela do dono.

## O que ainda reprova, e é decisão do dono

| Regra | O que ela mede | Estado |
|---|---|---|
| `PD6` | todo metal contra a área da antena, nos três eixos | o braço de alumínio fica **4,0 mm** abaixo da antena. A ficha do ME54BS13 pede 3 a 5: está na faixa de risco, **a medir na bancada** |
| `PD10` | o envelope contra `docs/02` | **73,5** de comprimento contra **38**; a largura e a altura cumprem. O comprimento vem da placa de 50 mm mais a célula ao lado ([12](../12-comparacao-com-a-classe.md#a-fundo-o-que-prende-o-comprimento)) |

## Massa

Estimada por volume e densidade (página 3 do PDF e regra `PD11`), nada
pesado: pod impresso 1,15 g/cm³, envase 1,0, FR-4 1,85, célula 2,0, peças
2,5 sobre 70 % do contorno de ocupação vezes a altura. Dá **13,4 g** contra
os 20 do alvo.

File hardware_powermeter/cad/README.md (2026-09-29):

# CAD da placa

Os geradores do KiCad 8: esquemático, placa, roteamento, verificações,
3D e desenhos. É a cadeia do ciclocomputador
(`hardware_gnssbike/cad/`), portada em 2026-09-27 com o nome de projeto
`pmeter`, as tabelas desta placa e três correções no roteador que esta
placa, mais densa e mais estreita, obrigou a fazer. Nada aqui é
desenhado à mão: cada arquivo `.kicad_*` sai de um script, e cada
script diz de que documento ou ficha tirou cada número.

**Nesta página:** [A cadeia](#a-cadeia) · [Os arquivos](#os-arquivos) · [O que mudou em relação ao ciclocomputador](#o-que-mudou-em-relação-ao-ciclocomputador) · [As regras do dry run](#as-regras-do-dry-run) · [Armadilhas](#armadilhas)

> [!WARNING]
> Nada foi fabricado nem montado. A placa existe como
> `pmeter.kicad_pcb`; o que foi medido está em
> [08](../08-dry-run-2026-09-27.md) e, depois da troca do modulo, em
> [10](../10-dry-run-2026-09-28.md).

## A cadeia

```mermaid
flowchart LR
    SCH["make_sch.py<br/>raiz + 4 folhas"] --> CSCH["check_sch.py<br/>ERC, netlist × nets.py,<br/>geometria"]
    CSCH --> PDF["kicad-cli sch export pdf<br/>esquematico/pmeter-esquematico.pdf"]
    DXF["make_dxf.py<br/>contorno e zonas"] --> CDXF["check_dxf.py"]
    CDXF --> PCB["make_pcb.py<br/>coloca as 58 peças"]
    PCB --> ROUTE["route.py<br/>labirinto A* em 3 camadas"]
    ROUTE --> FILL["fill_zones.py<br/>malhas, Python do KiCad"]
    FILL --> DRC1["kicad-cli pcb drc<br/>_drc_all.json"]
    DRC1 --> REP["reparar.py<br/>fecha o que o DRC diz aberto"]
    REP --> FILL2["fill_zones.py de novo"]
    FILL2 --> CPCB["check_pcb.py --como-esta<br/>DRC, contorno, redes"]
    CPCB --> DRY["dry_run_pcb.py<br/>24 regras das fichas"]
    DRY --> M3D["make_3d.py<br/>GLB e vistas placa-3d-*.png"]
    M3D --> M2D["make_2d.py · montagem.py<br/>placa/pmeter-pcb.pdf, pmeter-montagem.pdf"]
    M3D --> POD["pod/make_pod.py"]
```

Da raiz do repositório, com o Python do sistema salvo onde está dito:

```
python hardware_powermeter/cad/make_sch.py
python hardware_powermeter/cad/check_sch.py
"D:/KiCAD/bin/kicad-cli.exe" sch export pdf --output hardware_powermeter/esquematico/pmeter-esquematico.pdf hardware_powermeter/cad/pmeter.kicad_sch
python hardware_powermeter/cad/make_dxf.py
python hardware_powermeter/cad/check_dxf.py
python hardware_powermeter/cad/make_pcb.py
python hardware_powermeter/cad/route.py
"D:/KiCAD/bin/python.exe" hardware_powermeter/cad/fill_zones.py
cd hardware_powermeter/cad && "D:/KiCAD/bin/kicad-cli.exe" pcb drc --severity-all --format json -o _drc_all.json pmeter.kicad_pcb
python hardware_powermeter/cad/reparar.py
"D:/KiCAD/bin/python.exe" hardware_powermeter/cad/fill_zones.py
python hardware_powermeter/cad/check_pcb.py --como-esta
python hardware_powermeter/cad/dry_run_pcb.py
python hardware_powermeter/cad/make_3d.py
python hardware_powermeter/cad/make_2d.py
python hardware_powermeter/cad/montagem.py
python hardware_powermeter/pod/dry_run_pod.py
python hardware_powermeter/pod/make_pod.py
```

O tamanho da placa sai de `make_dxf.py` (`W`, `H`) e pode ser
experimentado sem editar o arquivo: `PMETER_W=48 python make_pcb.py`. O
colocador diz o que não coube e o roteador diz o que não ligou; foi assim
que o alvo de 48 × 16 de `docs/02` virou os **47 × 14** registrados em
[04](../04-placa.md#o-contorno).

## Os arquivos

| Arquivo | O que é |
|---|---|
| `parts.py` | as 58 peças com os pinos numerados pela ficha; `confirmed=False` marca as **duas** pinagens não lidas em ficha: o conector magnético genérico e o módulo de rádio, cujo mapa saiu do desenho mecânico do anúncio |
| `nets.py` | os 43 nós, pino a pino, e os pinos deixados abertos de propósito |
| `sheets.py`, `blocos.py`, `simbolos.py` | as 4 folhas, os blocos funcionais de cada uma e os símbolos da biblioteca do KiCad que têm a pinagem certa |
| `sch_lib.py`, `ksym.py`, `make_sch.py`, `check_sch.py`, `make_pro.py` | o gerador do esquemático, o leitor de símbolos do KiCad, o projeto `.kicad_pro` com as classes de rede |
| `make_dxf.py`, `check_dxf.py` | o contorno (`contorno.dxf`), o furo de fixação M1,6 e as zonas (`zonas.dxf`): a área livre da antena cerâmica, o bloco de energia a 20 mm do módulo, o conector magnético, o canto analógico, os furos da ponte, os sensores, o Tag-Connect, a sombra da célula e a da tampa |
| `footprints.py`, `fp_load.py` | qual footprint cada peça usa (biblioteca do KiCad ou gerado aqui com a cota da ficha), os corpos 3D em VRML, as alturas |
| `make_pcb.py` | o colocador: posições fixas (módulo, conector magnético, furos da ponte, conector da célula), âncoras por zona, desacoplamento encostado no pino, o resto por conectividade; os planos de terra e a área sem plano sob o nó de chaveamento |
| `route.py` | o roteador: vias de terra por pad, labirinto A* em `F.Cu`, `In2.Cu` e `B.Cu`, costura de terra na borda, poda de vias soltas. `PAR` está **vazio** desde 2026-09-28: não há mais par diferencial na placa |
| `route_neg.py` | o segundo estágio, de congestão negociada (PathFinder, McMurchie e Ebeling 1995), chamado quando o labirinto empaca; recebe como obstáculo o cobre que não vai rotear. Cada rodada refaz **só as redes que estão no caminho umas das outras**, e a cada `RIPAGEM_TOTAL` rodadas refaz a placa inteira do zero |
| `reparar.py` | fecha as ligações que o **DRC** ainda chama de abertas, na grade da placa pronta: parte sempre de um pad, mira o cobre inteiro da rede e recusa desenhar o que não encosta |
| `fill_zones.py` | preenche as malhas com o Python do KiCad (só ele sabe) |
| `check_pcb.py` | a placa como o KiCad a vê: DRC, peças presentes uma vez, redes dos pads, sobreposições, contorno, furos, cabe no envelope do pod, planos, serigrafia |
| `dry_run_pcb.py` | as regras das fichas e da IPC-2221 medidas na placa ([abaixo](#as-regras-do-dry-run)) |
| `make_3d.py`, `make_2d.py`, `montagem.py`, `orientacao.py` | o GLB e as vistas `placa-3d-*.png`, o PDF das camadas, o desenho de montagem, a conferência de para onde cada conector olha |
| `3d/` | os corpos VRML desenhados aqui; `3d/real/` (fora do git) para STEP de fabricante, quando houver |

## O que mudou em relação ao ciclocomputador

Tudo o que é desta placa está nas tabelas, não no código: zonas em
`make_dxf.py`, `ANCORAS`, `JUNTO`, `BORDA_FIXA`, `DECOPLA`, `ATRAS`,
`NAO_ENCOSTA` e `CHAVEIA` em `make_pcb.py`, `CORRENTE`, `CHAVEADOS`,
`ANALOGICO` e `TERMICOS` em `dry_run_pcb.py`. O que saiu: o receptor
GNSS, o display, o sensor de luz, o painel solar e as regras deles
(`RF5` a `RF8`, `RF10`, `AL4`, `OP1`). O que entrou: o canto analógico
(`AN1`, `AN2`), a face de trás plana (`ME2`), o envelope do pod (`ME1`).

Três coisas no roteador, todas **medidas** nesta placa em 2026-09-27
(`route.py` explica cada uma no lugar):

| O que | Antes | Agora |
|---|---|---|
| Ordem das ligações de uma rede | a ordem da lista de pinos: uma rede com um pino em cada ponta da placa e um pull-up no meio era buscada de uma ponta à outra primeiro, pelo meio apinhado, e falhava ali | **a mais perto primeiro**: a árvore cresce do pino mais próximo do que já está ligado |
| O pescoço dentro do campo de pads | um pescoço 0,025 mm mais largo que a trilha mínima, ou uma classe 0,07 mais estrita, pedia as células a 0,15 mm de cada lado livres, que num passo de 0,5 mm são a isolação do vizinho; **nenhum pino de potência do nPM1100, do ADS1220 ou do TVS conseguia sair do pad** (`veio=1`) | dentro do campo a busca olha só a célula; o pescoço tem a largura mínima em pad de até 0,3 mm (`estreitos − PASSO`); a classe USB fica nos 0,127 do fabricante (`make_pro.py`) |
| Até onde o pescoço dura | até `FOLGA` além da caixa dos pads: a primeira célula fora ainda estava dentro do anel do pad vizinho e a trilha larga não cabia ali (`veio=14`) | até `EXTRA_CAMPO` = `FOLGA` + meia trilha + um passo da grade |

E uma no colocador: os resistores de configuração e os pull-ups
(`NAO_ENCOSTA`) ficam perto do CI mas não encostam no pino, para deixar o
anel do nPM1100 para o desacoplamento e para as saídas dos pinos de
potência.

## As regras do dry run

`dry_run_pcb.py` mede a placa contra as fichas, e imprime o que mediu, o
que violou e o que não pôde medir. Uma regra que não acha o que medir
**falha dizendo isso**.

| Regra | O que mede | Fonte |
|---|---|---|
| RF1, RF3, RF4 | nada sobre a área da antena; 5 mm em volta dela sem peça alheia; a antena cerâmica dentro da zona livre **e encostando numa borda da placa** | guia de montagem do HOLYIOT-26001-A ([09](../09-modulo-de-radio.md#a-antena-manda-no-layout)) |
| RF9 | 20 mm do módulo a fonte chaveada ou indutor | 7.2, Interference Isolation Rule |
| US1 | as duas linhas da serial não atravessam o retângulo sem plano do nó de chaveamento do buck, em camada nenhuma | `make_pcb.sem_plano_no_chaveamento`; **não há mais par diferencial**: o nRF54L15 não tem USB e a 115200 baud não há impedância a controlar |
| AL1 | desacoplamento a 0,5 mm do pino do módulo, 2 mm nos outros CIs, 5 mm nos de reserva | 7.2; fichas do nPM1100, ADS1220, BMA400, TMP117, MAX17048 |
| AL5 | o filtro pi no pino de alimentação do módulo | 7.2 |
| AL2 | largura por corrente, 10 °C de subida | IPC-2221B, 6.2 |
| AN1 | o canto analógico a 4 mm do buck e a 5 mm do módulo | SBAS501D 9.4.1; os números são deste projeto |
| AN2 | o filtro das entradas e da referência junto dos pinos, e `REFP0` no nó da excitação | SBAS501D 9.1.2, figura 9-11; SBAA532A 3.1 |
| GN1, GN2 | pads de terra ligados, via por pad do módulo; costura na borda a cada 5 mm | 7.2; λ/10 a 2,44 GHz |
| AL6 | nenhuma via sob pad térmico | SBAS501D 11.1; nPM1100 PS 8.3 |
| ME1 | a placa no envelope alvo do pod (57,6 × 17,6 por dentro) | docs/02 |
| ME2 | as peças da frente sob o teto da tampa (2,7 mm), o conector que a atravessa exceto, e a face de trás plana | docs/02, Pod; `make_dxf.TETO_TAMPA` |
| ME3 | o corpo cotado na ficha cabe no footprint | `footprints.PACOTE` |
| ME4, ME5, ME6 | os corpos 3D contra as ilhas: só se medem com modelo de fabricante (nenhum ainda) ou GLB | o dono, no 3D do ciclocomputador |
| RT1 | zero itens desconectados no DRC completo (`--severity-all`) | kicad-cli |

Não medidas aqui: RF2 (o lado de RF para a borda: `orientacao.py`), AL3
(o laço de chaveamento: a bancada), e ME4 e ME5 enquanto não houver STEP
de fabricante em `3d/real/`.

## Armadilhas

As do ciclocomputador valem todas (`CLAUDE.md`, seção 6): o
`check_pcb.py` regera a placa sem `--como-esta`; o `fill_zones.py` só com
o Python do KiCad; o `kicad-cli` de `D:/KiCAD/bin`; um render de cima
sai girado 180°; o VRML da biblioteca do KiCad põe vírgula entre todos os
índices. As desta placa:

- **`PMETER_W` muda o contorno, e as zonas seguem** (`make_dxf.XE`,
  `XM`): o bloco de energia acaba 20 mm antes do módulo, o conector
  magnético e o canto analógico ficam no meio. Um número solto nas zonas
  quebra isso.
- **Os pontos de teste ficam atrás** (`ATRAS`): a face de trás tem de ser
  plana para a célula, e um pad é plano. Uma peça com corpo posta atrás
  falha `ME2` e `PD4`.
- **Os furos da ponte são passantes** (`PASSANTE`): ocupam as duas faces
  no colocador e todas as camadas no roteador.
- **Nenhum dos dois estágios do roteador sabe dizer se ligou** (medido em
  2026-09-28). O sequencial conta ligações que achou e o negociado conta
  caminhos que planejou; o negociado fechou dizendo "96 ligações, 0 células
  disputadas" com **onze pads sem cobre nenhum**, entre eles os três
  terminais do `USB_DM`. Pior: o critério de aceitação era `n_ok_n > n_ok`,
  ou seja, mais ligações — não menos pads abertos —, e ao aceitar o
  resultado do negociado o cobre sequencial das redes que ele **não** rodou
  ia para o lixo. Quem julga o roteamento é o DRC do KiCad, e é por isso
  que o `reparar.py` existe e entra na cadeia entre dois DRC.
- **Cobre herdado tem de ser obstáculo para quem herda.** Passar ao
  negociado as trilhas que ele não vai rotear (`pre_seg`, `pre_via`) levou
  o DRC de 182 violações para 25: sem isso ele planeja sobre placa vazia e
  o cobre herdado cai em cima das trilhas dele.
- **Uma via não é de graça.** Ela atravessa todas as camadas, então tem de
  se afastar de todas as redes em todas elas. Uma via posta sem essa
  conferência custou dois curtos, um isolamento de furo e uma ponte de
  máscara — quatro erros por uma ligação que nem fechou
  (`route.via_cabe_aqui`).
- **`SO_FRENTE` é preferência, não lei.** O par USB foi calculado como
  microstrip de 90 Ω em `F.Cu`, e com isso como lei o `USB_DM` não fecha
  (16,7 mm por uma face cheia). O aparelho fala **full speed**, 12 Mbit/s:
  a busca tenta a frente nas duas folgas e só troca de camada se não
  houver caminho — e avisa quando trocou.
- **Rotear depois do `fill_zones.py` custa 4 ligações e 45 trilhas**
  (medido em 2026-09-28, mesma colocação e mesmo código). Direto do
  `make_pcb.py`: 70 ligações na primeira passagem, 36 falhas, 440 segmentos,
  31 não roteados. Depois do preenchimento: 64, 42, 395, 35. **Esvaziar as
  malhas não devolve o resultado bom** — testado —, então não é o cobre
  despejado: é o arquivo inteiro, que o pcbnew reescreve à sua maneira. O
  `route.py` recusa rodar sobre placa preenchida e diz o que rodar antes.
  E o roteador **é determinístico**: duas execuções da mesma entrada dão o
  mesmo arquivo, o que foi medido para descartar a outra hipótese.
- **O passe de encosto final também tem de medir.** Ele liga uma trilha que
  parou a um passo do próprio pad, e desenhava sem conferir nada: um pad
  aberto por 0,15 mm virava um curto de 1,4 mm de trilha. O roteador via os
  cinco pares perto demais, dizia, e gravava a placa. Hoje cada toco é
  medido antes de ser aceito e o que não passa deixa o pad aberto dizendo
  por quê.
- **O que NAO fecha as ligacoes que faltam** (tudo medido em 2026-09-29,
  sobre a placa com o modulo ligado; a linha de base e 30 itens
  desconectados com 0 erros de DRC e 16 regras cumpridas):

  | Tentativa | Resultado |
  |---|---|
  | Placa de 50 ou 52 mm | 33 desconectados. **Nao e falta de area**: a ocupacao e 23 % das tres camadas |
  | Trilha de sinal a 0,127 mm (o minimo declarado) | **identico**. O passo da grade e 0,15 mm, entao 0,023 mm nao muda uma celula |
  | Grade de 0,10 mm | 32, com 2 erros, e 8,5 min de roteamento |
  | Anel livre de 0,9 mm em volta dos CIs de passo fino | **nenhuma peca se moveu**: elas ja guardavam essa distancia |
  | Anel de 1,6 mm nos quatro CIs + folga de mascara 0,20 | 28, mas duas regras a menos (o desacoplamento afasta) |
  | Folga de mascara 0,20 / 0,14 | 29 / 28, a segunda com 3 erros de isolamento |
  | Celula movida para a direita + passivos de energia no verso | 32 |
  | Cinco ordens de roteamento diferentes | 11 a 43: **so troca quais redes falham** |

- **O fanout e o caminho, e ainda nao esta pronto.** Tirar cada ilha de
  passo fino para uma via ANTES de rotear - com a placa vazia - levou as
  redes que falham de **23 para 12** e as ligacoes roteadas de 81 para 85.
  Mas o numero do DRC piorou (30 para 42), porque o cobre do fanout que o
  roteamento nao usa vira fragmento e conta como item desconectado, e podar
  so o que sobra ainda nao ficou certo. E o passe **existe** em `pre_ligados`:
  o laco principal ja sabe partir de cobre pre-desenhado. E por aqui que a
  proxima rodada comeca.
- **O conector magnético é genérico**: `confirmed=False` em `parts.py`,
  e a janela da tampa segue o contorno dele; trocar a peça é trocar o
  footprint, a altura e rodar os dois dry runs.
- **Rip-up parcial sozinho DIVERGE nesta placa** (medido em 2026-09-28). O
  PathFinder refaz só as redes que estão no caminho umas das outras, e numa
  placa grande isso é quase todo mundo; aqui o teste de partilha é
  geométrico e acha poucas redes, então o conjunto fica pequeno e a pressão
  bate numa parede: as culpadas não têm para onde ir porque as inocentes
  estão congeladas, e o custo histórico não empurra quem nunca é refeito.
  As células disputadas subiram rodada após rodada — 420, 488, 528, 611,
  972, 1292, **1588 na rodada 10**, com duas ligações perdendo o caminho. A
  saída é a que a literatura usa quando o rip-up é parcial: uma **ripagem
  total a cada `RIPAGEM_TOTAL` rodadas** (hoje 6). As rodadas baratas
  refinam, a rodada cheia redistribui — e de quebra lava qualquer marca
  velha que um rip-up incremental tenha deixado em `uso`, que é o modo de
  falhar de um `_desmarcar` que não seja o inverso exato do `_marcar`. Com
  ela, as rodadas cheias caíram para 234, 199, 155 e 120.
- **As redes culpadas têm de ser anotadas onde o conflito é achado.** A
  célula que entra em `disputadas` é a do **caminho**, e o conflito está numa
  célula do disco de folga dele: procurar depois quem está nela em `uso`
  devolve a própria rede e quase nunca a outra, então a outra nunca era
  refeita e a rodada seguinte achava o mesmo conflito para sempre.

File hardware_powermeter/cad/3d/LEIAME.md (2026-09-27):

# Corpos 3D das peças

Das 113 peças da placa, **85 usam o modelo STEP da própria biblioteca do
KiCad** e aparecem sem que ninguém faça nada. As **18** desta página o KiCad
não tem, e para elas este projeto **desenha uma caixa** com a medida do
encapsulamento. As outras 5 (o furo M2, os três pontos de teste e os pads do
Tag-Connect) não têm corpo, e isso está certo: um ponto de teste é um pad.

> [!NOTE]
> Os `.wrl` desta pasta são **gerados** por
> [`../footprints.py`](../footprints.py) a cada `make_pcb.py`. Não os edite:
> a próxima execução os reescreve.

## Como pôr um modelo de verdade

Baixe o STEP do fabricante (ou do SnapEDA, Ultra Librarian, Mouser, DigiKey)
e salve em **`3d/real/`** com o **nome do footprint**. O gerador prefere o que
estiver lá e nem escreve a caixa:

```text
cad/3d/real/SW_SPST_B3S-1000.step
cad/3d/real/USB_C_Receptacle_Palconn_UTC16-G.step
```

Aceita `.step`, `.stp` e `.wrl`, nessa ordem. **STEP é melhor**: é o único
formato que a exportação GLB e STEP do KiCad lê, então só ele aparece na
imagem gerada por `make_3d.py`. Um `.wrl` aparece apenas no visualizador 3D
do KiCad.

> [!WARNING]
> **`3d/real/` não vai para o repositório.** Este repositório é público e um
> modelo 3D de fabricante vem com os termos do fabricante — a mesma razão que
> mantém as fichas fora de [`../../datasheets/`](../../datasheets/). O
> `.gitignore` da pasta cuida disso. Os `.wrl` gerados também ficam de fora,
> como todo arquivo gerado neste repositório: quem os reconstrói é o
> `make_pcb.py`. O que é versionado é o **gerador**, em
> [`../footprints.py`](../footprints.py).

## As 18 peças, e o que procurar

Nome do footprint é o nome do arquivo a salvar em `3d/real/`.

| Footprint | Peça a procurar | Medida usada (mm) | Altura: de onde veio |
|---|---|---|---|
| `SW_SPST_B3S-1000` | Omron **B3S-1002P** | 6,00 × 6,60 × **5,00** | corpo de 3,5 mais o botão — **conferir na ficha da Omron** |
| `USB_C_Receptacle_Palconn_UTC16-G` | Molex **2036150003** | 8,94 × 7,32 × **3,26** | altura corrente de receptáculo USB-C — **conferir na ficha do Molex** |
| `Buzzer_CUI_CPT-9019S-SMT` | CUI **CPT-1117-83-SMT** | 9,00 × 9,00 × **3,00** | **conferir**: a lista de compras traz o CPT-1117, não o CPT-9019S |
| `TE_0-1734839-5_1x05-1MP_P0.5mm_Horizontal` | Molex **503480-0500** | 7,93 × 4,40 × **1,20** | **conferir**: a peça ainda não está escolhida ([06](../../06-conectores-e-pontos-de-teste.md)) |
| `SOIC-8_5.23x5.23mm_P1.27mm` | Macronix **MX25R6435F** | 5,23 × 5,23 × 2,00 | altura normal do SOIC-8 |
| `QFN-28-1EP_4x4mm_P0.4mm_EP2.3x2.3mm` | e-peas **AEM10900** | 4,00 × 4,00 × 0,90 | altura normal de um QFN |
| `Texas_X2SON-4_1x1mm_P0.65mm` | TI **TPS7A0218PDQN** | 1,00 × 1,00 × 0,40 | altura normal do X2SON |
| `SOT-523` | Diodes **DMG1012T-7** | 0,80 × 1,60 × 0,60 | altura normal do SOT-523 |
| `MinewSemi_ME54BS13_16.5x12mm` | MinewSemi **ME54BS13** | 12,00 × 16,50 × 2,40 | **ficha V1.0.0, desenho mecânico** |
| `u-blox_MAX-F10S_9.7x10.1mm` | u-blox **MAX-F10S** | 9,70 × 10,10 × 2,40 | medida do encapsulamento MAX |
| `MAX17262_WLP-9_1.4x1.4mm_P0.4mm` | Analog **MAX17262REWL** | 1,40 × 1,40 × 0,50 | ficha |
| `BMP585_LGA-8_3.25x3.25mm` | Bosch **BMP585** | 3,25 × 3,25 × 1,96 | ficha |
| `MMC5633_WLP-4_0.85x0.85mm` | MEMSIC **MMC5633NJL** | 0,85 × 0,85 × 0,40 | ficha |
| `OPT3001_USON-6_2x2mm_P0.65mm` | TI **OPT3001DNPR** | 2,00 × 2,00 × 0,65 | ficha |
| `TXU0204_WQFN-14_3x2.5mm_P0.5mm` | TI **TXU0204BQAR** | 3,00 × 2,50 × 0,80 | ficha |
| `TPD4E05U06_USON-10_1x2.5mm_P0.5mm` | TI **TPD4E05U06DQAR** | 1,00 × 2,50 × 0,55 | ficha |
| `ESD761_X1SON-2_1x0.6mm` | **ESD761DPYR** | 1,00 × 0,60 × 0,45 | ficha |
| `LED_RGB_APTF1616_1.6x1.6mm` | Kingbright **APTF1616SEEZGKQBKC** | 1,60 × 1,60 × 0,70 | ficha |

### As duas que valem mais a pena

Os dois módulos são os únicos desenhados com mais de um bloco, porque neles a
forma diz alguma coisa:

- **ME54BS13** — substrato de 12,00 × 16,50 × 0,80 mm, blindagem metálica de
  1,60 mm sobre tudo **menos os 4,46 mm da ponta**, que é a antena e fica
  aberta. É o que o desenho mecânico da ficha V1.0.0 mostra, e é o que
  permite ver na imagem que a antena olha para a borda.
- **MAX-F10S** — substrato mais blindagem sobre a peça inteira, que é por que
  o manual de integração pode pedir terra por baixo dela ([§4.4](../../08-dry-run-2026-09-27.md)).

**Nenhum dos dois fabricantes publica STEP.** A página do ME54BS13 na
MinewSemi e a loja deles listam só a ficha; a da u-blox não responde a
requisição automática. Por isso esses dois foram **desenhados a partir das
cotas**, não baixados.

## Prioridade, se for baixar

Só quatro alturas mudam alguma coisa, e são as das peças altas, que decidem se
a tampa fecha: a **tecla** (5,0 mm), o **USB-C** (3,26), o **buzzer** (3,0) e
o **conector da luz** (1,2). As outras catorze ficam abaixo de 2,4 mm, bem
dentro dos 2,6 mm que a sombra do display deixa
([04](../../04-placa.md#zonas-proibidas)).

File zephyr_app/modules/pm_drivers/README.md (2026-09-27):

# Drivers próprios

- `adc/ads1220`: conversor da ponte (SPI, ganho 128, referência ratiométrica, duty-cycle). O Zephyr v3.3.0 traz `ads1x4s0x` (ADS124S06) e `ad4130`, não o ADS1220.

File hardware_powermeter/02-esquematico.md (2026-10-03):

# Folhas do esquemático

As quatro folhas, bloco a bloco. Cada uma traz o circuito, as decisões que
não aparecem no desenho e o que fica em aberto. As ligações completas
estão na [lista de nós](03-netlist.md), as peças em [05](05-materiais.md) e
os contatos de cada conector em [06](06-conectores-e-pontos-de-teste.md).
O PDF gerado está em [`esquematico/pmeter-esquematico.pdf`](esquematico/pmeter-esquematico.pdf).

**Nesta página:** [Como as folhas são desenhadas](#como-as-folhas-são-desenhadas) · [Folha 1 · Energia](#folha-1--energia) · [Folha 2 · MCU e depuração](#folha-2--mcu-e-depuração) · [Folha 3 · Ponte e conversor](#folha-3--ponte-e-conversor) · [Folha 4 · Sensores](#folha-4--sensores) · [Verificação](#verificação)

> [!WARNING]
> Nada aqui foi montado. O esquemático e a placa existem como arquivos de
> CAD ([04](04-placa.md)); nenhuma placa foi fabricada e nenhum componente
> passou por bancada. Toda pinagem foi lida na ficha do fabricante, e a
> única peça cuja numeração **não** vem de ficha é o conector magnético
> ([06](06-conectores-e-pontos-de-teste.md#j101--conector-magnético)).

## Como as folhas são desenhadas

O gerador é o do ciclocomputador, portado sem mudar o padrão
(`cad/make_sch.py` com `cad/blocos.py`, `cad/sheets.py` e `cad/simbolos.py`;
[`cad/README.md`](cad/README.md)). É o que o dono pediu em 2026-09-27:
a mesma ideia e o mesmo desenho, para as duas placas serem lidas do mesmo
jeito.

- a **raiz** é um diagrama de blocos, um por folha, com os sinais que
  atravessam folhas desenhados entre os blocos;
- cada folha tem **blocos funcionais** na ordem em que o sinal flui, cada
  um numa caixa tracejada com título;
- dentro do bloco, o **passivo ao lado do pino que serve**, do lado para
  onde o pino aponta, e o desacoplamento numa prateleira sob o CI;
- **alimentação e terra por símbolo**: `VBUS`, `VBAT`, `VSYS`, `3V0`,
  `3V0_MOD`, `3V0_EXC` e `GND` nunca viajam por fio entre blocos;
- sinal que sai do bloco vira **rótulo local**; sinal que sai da folha,
  **rótulo hierárquico**, os dois num toco curto saído do pino;
- só o conector da célula toma símbolo da biblioteca do KiCad; os CIs e
  o módulo saem como retângulos com os pinos nomeados e numerados pela
  ficha, porque um símbolo bonito com o fio no pino errado é pior que um
  retângulo certo;
- tudo em A4, grade de 50 mil.

```mermaid
flowchart LR
    subgraph F1["1 Energia"]
        J101["J101 conector<br/>magnético"] --> D101["D101 TVS"]
        J101 -->|"VBUS"| U101["U101 nPM1100"]
        U101 -->|"3V0"| OUT1(("3V0"))
        J102["J102 célula"] -->|"VBAT"| U101
        J102 --> U102["U102 MAX17048"]
    end
    subgraph F2["2 MCU e depuração"]
        U201["U201 HOLYIOT-26001-A"]
        J201["J201 Tag-Connect"] --> U201
        U201 --> D201["D201 LED RGB"]
    end
    subgraph F3["3 Ponte e conversor"]
        J301["J301 furos<br/>da ponte"] --> U301["U301 ADS1220"]
        U302["U302 TPS22916"] -->|"3V0_EXC"| J301
    end
    subgraph F4["4 Sensores"]
        U401["U401 BMA400"]
        U402["U402 TMP117"]
    end
    D101 -->|"USB, SWD"| U201
    U101 -->|"CHG, ERR, SHPACT"| U201
    U102 -->|"I2C"| U201
    U301 -->|"SPI, DRDY"| U201
    U201 -->|"EXC_EN"| U302
    U401 -->|"SPI, INT1"| U201
    U402 -->|"I2C"| U201
```

## Folha 1 · Energia

Uma entrada de 5 V pelo conector magnético, uma célula, um trilho de saída.

```mermaid
flowchart LR
    CON["J101 magnético<br/>5 V · GND · D+ · D− · SWDIO · SWCLK"]
    TVS["D101 TPD4E05U06<br/>4 canais, passagem direta"]
    CON -->|"D+, D−, SWDIO, SWCLK"| TVS
    CON -->|"VBUS"| NPM["U101 nPM1100"]
    TVS -->|"D+, D−"| NPM
    TVS -->|"D+, D−"| MOD(("módulo, pads 7 e 8"))
    TVS -->|"SWDIO_J, SWCLK_J"| RS["R107, R108<br/>100 Ω"] --> SWD(("SWDIO, SWDCLK"))
    CELL["LiPo 501415<br/>≥ 81 mAh, com proteção"] -->|"J102 JST SH"| VBAT(("VBAT"))
    VBAT --> NPM
    VBAT --> GAUGE["U102 MAX17048"]
    NPM -->|"SW · L101 2,2 µH"| R3V0(("3V0"))
    NPM -->|"VSYS"| VSYS(("VSYS"))
    NPM -->|"CHG, ERR"| MCU(("módulo"))
    MCU -->|"SHPACT"| NPM
    GAUGE -->|"I2C, ALRT"| MCU
```

### As decisões desta folha

**O nPM1100 é configurado por pino, sem interface.** `VOUTBSET0` e
`VOUTBSET1` altos dão 3,0 V no buck (tabela da 6.3.1 do PS v1.5);
`VTERMSET` alto dá 4,2 V de terminação (tabela 12); `ISET` no `AVSS`
deixa a detecção da porta decidir entre 100 e 500 mA (tabela 10); `MODE`
baixo é o modo automático do buck; `ICHG` de 6,8 kΩ dá cerca de 75 mA
(625 / 0,0747 − 1562,5, equação da 6.2.4), 0,5 C de uma célula de
150 mAh; sem termistor no pack, `NTC` leva 10 kΩ ao `AVSS` (6.2.5). Os
três pinos estáticos penduram no `VSYS` e não no `3V0`, porque o `VSYS`
existe antes de o buck ligar.

**D+ e D− vão ao nPM1100 e ao módulo, os dois.** O PS v1.5 (7.3) desenha
exatamente isso: o nPM1100 detecta o tipo de porta e o SoC espera a
detecção terminar antes de ligar o seu USB. O trilho `VBUS` também chega
ao pad 9 do módulo, que é o detector de USB do SoC (a placa não alimenta
nada por ele).

**Ship mode sem botão.** `SHPHLD` fica só no pull-up de 1 MΩ ao `VBAT`
(`R106`); o firmware entra em ship mode levando `SHPACT` alto por 200 ms
sem cabo, e o pod só sai dele com o cabo, porque o `VBUS` acorda o
nPM1100 (3.5). É o estado de fábrica e de guarda longa, 460 nA.

**O medidor lê a célula pelo `VDD`.** No MAX17048 o pino `CELL` não é
ligado internamente (ficha, página 6): o CI mede a tensão no próprio
`VDD`, que é o `VBAT`; `CTG` e `QSTRT` vão ao terra como a ficha manda
quando não são usados. Não há resistor de sentido: o ModelGauge estima a
carga pela tensão.

**A proteção dos sinais fica no conector, não no módulo.** O
TPD4E05U06 em USON-10 usa os quatro pinos `NC` como passagem direta
(tabela 4-2 do SLVSBO7O: "used for optional straight-through routing"): o
sinal entra por um lado e sai pelo pino da frente, que é a única forma de
um par atravessar uma peça de 0,5 mm de passo sem contorná-la. Os 100 Ω
em série no SWD ficam **depois** do TVS, entre ele e o módulo.

**Os pontos de teste ficam na face de trás.** `TP101` a `TP104` medem
`VBUS`, `VBAT`, `3V0` e `GND` na bancada, com a placa fora do pod; dentro
do pod a única porta é o conector magnético, e a face de trás tem de ser
plana porque a célula encosta nela ([07](07-pod.md)).

### Em aberto nesta folha

- o conector magnético é **genérico**: a peça, o passo real, a numeração
  e o footprint mudam quando um fornecedor for alcançado
  ([06](06-conectores-e-pontos-de-teste.md#j101--conector-magnético));
- a polaridade do `J102` (1 = `VBAT+`, 2 = `GND`) é escolha deste projeto e
  vai ao fabricante do pack;
- os códigos LCSC do nPM1100, do MAX17048 e do JST estão marcados "a
  conferir" em [05](05-materiais.md).

## Folha 2 · MCU e depuração

```mermaid
flowchart LR
    MOD["U201 HOLYIOT-26001-A<br/>nRF54L15"]
    FB["FB201 600 Ω<br/>C203 · C201 · C202"] -->|"3V0_MOD"| MOD
    R3V0(("3V0")) --> FB
    TC["J201 Tag-Connect<br/>TC2030-NL"] -->|"SWDIO, SWDCLK, RESET"| MOD
    MOD -->|"LED_R, LED_G, LED_B<br/>R201 a R203, 1,5 kΩ"| LED["D201 RGB<br/>anodo no VSYS"]
    MOD -->|"UART_TX, UART_RX"| TP["TP201, TP202<br/>face de trás"]
    PU["R204, R205<br/>4,7 kΩ ao 3V0"] --- MOD
```

### As decisões desta folha

**O filtro pi do módulo continua, agora por decisão do projeto.** Quem
pedia o footprint era a ficha do ME54BS13 (7.2, Power Supply Design), e o
HOLYIOT-26001-A **não tem ficha**: o fabricante publica só o desenho
mecânico. O filtro fica porque a razão dele não mudou — o `3V0` vem de um
buck chaveado e a peça é um rádio —, e porque tirá-lo depois custa uma
revisão de placa enquanto deixá-lo custa dois 0402: `C203` de 4,7 µF antes
do ferrite `FB201`, `C201` de 100 nF a 0,5 mm do pad 15 (`VDD`) e `C202` de
4,7 µF do lado do módulo. O ferrite pode virar 0 Ω na montagem.

**Os pinos são os de [`docs/02`](../docs/02-hardware.md#pinos-do-módulo).**
`SPI00` em P2.01 (clock), P2.02, P2.04, com `ADC_CS` P2.05, `ADC_DRDY`
P2.03, `IMU_CS` P2.07 e `IMU_INT1` P2.08; `I2C22` em P1.11 (clock) e
P1.12; `EXC_EN` P2.06; `CHG_N` P1.09; `ERR_N` P1.08; `SHPACT` P1.15;
`GAUGE_ALRT` P1.07; `VBUS_SENSE` P1.06; LED em P1.10, P1.13 e P1.14;
`UART20` em P1.04 e P1.05. Nenhum deles é escolha de gosto: o `SCL` de um
TWIM e o `SCK` de um SPIM precisam de pino com clock, e a lista usada é a
dos pinos que a **própria Nordic** usa no NCS para cada periférico
([09](09-modulo-de-radio.md#o-mapa-de-pinos-do-projeto)). O de-para para o
pad do módulo é a tabela `PADS_HOLYIOT` de [`cad/parts.py`](cad/parts.py),
os 36 pads lidos no desenho do fabricante, e ela ainda precisa ser
conferida num módulo real.

**O LED é de anodo comum no `VSYS`** e os catodos descem por 1,5 kΩ a
pinos do módulo em nível baixo: com 5 V do cabo são 2 mA por cor; na
célula, 0,7 mA. O LED escolhido é muito mais brilhante que o do
ciclocomputador, e os 1,5 kΩ são o valor de partida a recalcular na
bancada ([`cad/footprints.py`](cad/footprints.py) diz o mesmo).

**Os pull-ups do I2C ficam junto do mestre**, e não junto de um dos
escravos: 4,7 kΩ para um barramento de dois escravos a 100 kHz.

**Dois SWD.** O Tag-Connect (`J201`) grava a placa nua na fábrica e na
bancada; o conector magnético leva `SWDIO` e `SWCLK` para fora do pod
fechado, pelos 100 Ω. Os dois chegam aos mesmos pads 5 e 6 do módulo.

### Em aberto nesta folha

- o valor dos resistores do LED, a acertar com a peça na mão;
- o console pelos pontos de teste não sai do pod: dentro dele o log vai
  por BLE ([`docs/04`](../docs/04-arquitetura-firmware.md)).

## Folha 3 · Ponte e conversor

```mermaid
flowchart LR
    R3V0(("3V0")) --> SW["U302 TPS22916<br/>ON = EXC_EN"]
    SW -->|"3V0_EXC · C307"| J["J301 furos<br/>E+ · S+ · S− · E− · SH"]
    SW -->|"3V0_EXC · C304"| REF["REFP0 do ADS1220<br/>REFN0 no terra"]
    J -->|"S+ · R301 1 kΩ"| AINP["AIN0"]
    J -->|"S− · R302 1 kΩ"| AINN["AIN1"]
    AINP --- C301["C301 47 nF C0G<br/>diferencial"] --- AINN
    AINP --- C302["C302 4,7 nF C0G"]
    AINN --- C303["C303 4,7 nF C0G"]
    AINP --> ADC["U301 ADS1220<br/>ganho 128, 175 SPS"]
    AINN --> ADC
    ADC -->|"SPI, DRDY"| MCU(("módulo"))
```

### As decisões desta folha

**A medição é ratiométrica.** A referência externa `REFP0` é o mesmo nó
que excita a ponte, `3V0_EXC`, e `REFN0` é o terra da ponte: qualquer
deriva da excitação sai da conta (SBAA532A, 3.1). É por isso que a chave
alimenta a ponte **e** a referência, e por isso que `C304` fica na
referência e não no trilho.

**O filtro é o da figura 9-11 do SBAS501D.** 1 kΩ em série em cada
entrada, 47 nF C0G diferencial e 4,7 nF C0G de modo comum em cada
entrada, dez vezes menor que o diferencial para que o descasamento dos
dois não vire sinal diferencial. O corte diferencial fica em 1,7 kHz e o
de modo comum em 34 kHz (**conta** deste projeto; a ficha dá a topologia,
não os valores). Só C0G: um X7R nas entradas de um conversor de 24 bits
é um microfone e um termômetro.

**`AIN2` e `AIN3` ficam abertos**, como a 9.1.5 manda para entradas não
usadas; `CLK` vai ao `DGND` para o oscilador interno. O pad térmico vai ao
`AVSS` sem via por baixo ([regra `AL6`](cad/README.md#as-regras-do-dry-run)).

**A excitação é chaveada pelo firmware**, não pela `PSW` interna do
ADS1220: com 1 kΩ a ponte puxa 3 mA e o firmware desliga a chave fora de
`Active` e `Calibrating` ([`docs/02`](../docs/02-hardware.md#orçamento-de-consumo)
diz o que isso custa e o que não resolve). O TPS22916B liga em 140 µs a
3,6 V e o `VOUT` assenta em `C307` antes da primeira conversão.

**Os fios da ponte chegam por furos, não por pads.** Cinco furos
metalizados de 0,9 mm (`J301`): os fios sobem do braço do pedivela por um
rasgo no fundo do pod, direto sob os furos, e a solda no furo segura o fio
onde um pad na face de cima exigiria dobrá-lo pela borda
([07](07-pod.md)). O quinto furo é a blindagem do cabo, ao terra.

### Em aberto nesta folha

- os extensômetros (resistência, padrão e cola) são decisão de
  [`docs/06`](../docs/06-medicao-e-calibracao.md) e não desta folha;
- a temporização entre `EXC_EN`, o `START` e o `DRDY` se decide na
  bancada.

## Folha 4 · Sensores

```mermaid
flowchart LR
    IMU["U401 BMA400<br/>SPI 4 fios · INT1"] -->|"SPI, IMU_INT1"| MCU(("módulo"))
    TMP["U402 TMP117<br/>ADD0 no terra: 0x48"] -->|"I2C"| MCU
    R3V0(("3V0")) --> IMU
    R3V0 --> TMP
```

### As decisões desta folha

**O BMA400 fala SPI de 4 fios**, no mesmo `SPI00` do conversor, com `CSB`
próprio (`IMU_CS`) e `INT1` para acordar o SoC do `$SLEEP`; `INT2`, `NC` e
os dois pads sem função ficam abertos. `VDD` e `VDDIO` no `3V0`, cada um
com o seu 100 nF.

**O TMP117 mede a ponte, não o ar.** Fica na placa ao lado dos furos da
ponte, o mais perto que a placa permite do braço; `ADD0` no terra dá o
endereço 0x48, e `ALERT` fica aberto porque a leitura é a 1 Hz pelo
firmware.

### Em aberto nesta folha

- a curva de temperatura da ponte é calibração ([`docs/06`](../docs/06-medicao-e-calibracao.md)),
  e o lugar do TMP117 na placa é o que o colocador conseguiu ao lado dos
  furos: a distância real está em [04](04-placa.md).

## Verificação

`python cad/make_sch.py` gera a raiz e as quatro folhas;
`python cad/check_sch.py` roda o ERC do KiCad, exporta o netlist e o
compara com [`cad/nets.py`](cad/nets.py) pino a pino, confere os 12 pinos
deixados abertos de propósito e a geometria de cada folha (fio sobre
componente, peça fora da folha, peça sobre peça, rótulos hierárquicos
contra os pinos dos blocos). O resultado de 2026-09-27 está em
[08](08-dry-run-2026-09-27.md).

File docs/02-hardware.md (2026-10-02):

# Hardware: requisitos, blocos e o pod

O que o módulo tem de cumprir, o que cada bloco faz e o tamanho que o pod pode ter. A lista de peças com os datasheets está em [`../hardware_powermeter/01-lista-de-componentes.md`](../hardware_powermeter/01-lista-de-componentes.md).

**Nesta página:** [Requisitos](#requisitos) · [Blocos e trilhos](#blocos-e-trilhos) · [Orçamento de consumo](#orçamento-de-consumo) · [Pinos do módulo](#pinos-do-módulo) · [Placa](#placa) · [Pod](#pod) · [Conector magnético](#conector-magnético)

## Requisitos

| Requisito | Valor | De onde vem |
|---|---|---|
| Massa do módulo com bateria | ≤ 20 g | o piso da classe de produto ([01](01-visao-geral.md#a-classe-de-produto)) |
| Envelope do pod | **38 × 20 × 10 mm**, nas três medidas, com prioridade para o comprimento. O dono pediu em 2026-09-27 que o aparelho montado fique perto do da classe, e a medida por fotogrametria ([01](01-visao-geral.md#o-envelope-da-classe-medido-por-fotogrametria)) mostrou que a classe faz isso em 37 a 39 mm de comprimento, não nos 60 que este projeto perseguia. O limite duro continua sendo a largura da face interna do braço esquerdo e a folga até o quadro, **medidas no pedivela do dono antes de fechar a placa** | medido na foto de imprensa do fabricante, com o braço de 170 mm como régua e o passo dos contatos de carga como conferência; ninguém publica os números |
| Precisão | ±2 % contra referência na fase 1; ±1,5 % como meta da fase 2 | classe de produto; [06](06-medicao-e-calibracao.md#orçamento-de-erro) |
| Faixas | 0 a 2000 W; 10 a 200 rpm; −10 a +50 °C | classe de produto; temperatura pelo mais restrito dos componentes (LiPo) |
| Autonomia | ≥ 50 h pedalando por carga; ≥ 6 meses parado | classe de produto; [orçamento](#orçamento-de-consumo) |
| Amostragem | ponte a 175 amostras/s com ganho 128; acelerômetro a 100 Hz | ADS1220 (SBAS501D), BMA400 |
| Rádio | BLE Cycling Power Service 1.1 e ANT+ Bicycle Power, ao mesmo tempo | [05](05-protocolos.md) |
| Configuração | comprimento do pedivela, zero, inclinação, curva de temperatura, lado e identificação, gravados por BLE | [05](05-protocolos.md#serviço-de-configuração) |
| Atualização | por BLE (mcumgr sobre MCUboot) e por USB (recuperação serial do MCUboot) | [04](04-arquitetura-firmware.md#atualização) |
| Carga e dados | conector magnético de 6 pinos: 5 V, GND, D+, D−, SWDIO, SWCLK. **Decisão do dono em 2026-09-27**, mantida mesmo com a placa encolhendo: o produto da classe usa só dois contatos e faz dados apenas por rádio, e aqui as seis vias ficam, porque o USB e o SWD pelo cabo são o que torna o aparelho gravável e depurável sem abrir o pod | [conector](#conector-magnético) |
| Proteção | IPX7: pod envasado, junta na face do conector | classe de produto |
| Placa | 4 camadas, 0,8 mm, área livre da antena do módulo pelas regras do fabricante | [placa](#placa) |

## Blocos e trilhos

```mermaid
flowchart LR
    subgraph SENSOR["Sensor"]
        B["Ponte completa 5 kΩ<br/>4 grades ativas"]
        SW["TPS22916<br/>excitação chaveada"]
        A["ADS1220<br/>REFP0/REFN0 = excitação"]
        SW --> B --> A
        SW --> A
    end
    subgraph MOV["Movimento e ambiente"]
        I["BMA400<br/>SPI, INT1"]
        T["TMP117<br/>I2C, junto da ponte"]
    end
    subgraph MCU["Módulo de rádio"]
        M["HOLYIOT-26001-A<br/>nRF54L15"]
    end
    subgraph EN["Energia"]
        P["nPM1100<br/>carga + buck 3,0 V"]
        BAT["LiPo 81 mAh<br/>15 × 14 × 5,0, com proteção"]
        F["MAX17048<br/>I2C"]
        P --- BAT
        BAT --- F
    end
    subgraph CON["Conector magnético"]
        C["5 V · GND · D+ · D− · SWDIO · SWCLK"]
        E["TPD4E05U06<br/>TVS nos 4 sinais"]
    end
    A -- "SPI, DRDY" --> M
    I -- "SPI, INT" --> M
    T -- "I2C" --> M
    F -- "I2C" --> M
    P -- "3,0 V" --> M
    P -- "3,0 V" --> SW
    P -- "CHG, ERR" --> M
    C -- "5 V" --> P
    C -- "D+, D−" --> M
    C -- "SWD" --> M
    E --- C
```

| Trilho | Origem | Quem usa | Observação |
|---|---|---|---|
| `VBAT` | célula | nPM1100, MAX17048 | célula com proteção própria |
| `VBUS` | conector | nPM1100 | 4,1 a 6,7 V de operação, 20 V absoluto (PS v1.5) |
| `3V0` | buck do nPM1100 | módulo, ADS1220 (AVDD e DVDD), BMA400, TMP117, TVS | 150 mA disponíveis; o módulo transmite com dezenas de mA |
| `3V0_EXC` | TPS22916 a partir de `3V0` | ponte e REFP0 do ADS1220 | ligado enquanto o conversor converte (`Active`, `Calibrating` e as rajadas de `Idle`), desligado no resto; a mesma tensão na referência faz a medição ratiométrica (SBAA532A, 3.1) |

## Orçamento de consumo

Estimativas de projeto a partir dos datasheets; nenhuma medida ainda.

| Estado | Bloco | Corrente | Base |
|---|---|---|---|
| Pedalando | ponte de **5 kΩ** a 3,0 V, ligada durante toda a conversão | 0,6 mA | 3,0 V / 5 kΩ; o filtro digital do ADS1220 integra a conversão inteira (SBAS501D, 8.3.6), então não existe janela de excitação menor que a própria conversão |
| Pedalando | ADS1220 modo normal, ganho 128 | 0,59 mA | 510 + 75 µA (SBAS501D) |
| Pedalando | BMA400 modo normal, OSR 0 | 0,004 mA | 3,5 µA |
| Pedalando | TMP117 a 1 Hz | 0,004 mA | 3,5 µA |
| Pedalando | nRF54L15 com BLE a 1 Hz e ANT+ a 4 Hz | 0,3 mA | estimativa de projeto; medir no DK |
| Pedalando | MAX17048 | 0,003 mA | 3 µA em hibernate |
| **Pedalando, total** | | **≈ 1,5 mA** em conversão contínua, **0,68 mA** com o conversor em duty-cycle | a célula que cabe no pod é 15 × 14 × 5,0 e vale **~81 mAh**: 54 h contínuo, **119 h em duty-cycle**, que é o modo decidido. Com a ponte de 1 kΩ eram 3,9 mA e 20 h |
| Parado | BMA400 a 100 Hz, ADS1220 em power-down entre rajadas de 8 amostras a cada 10 s, MCU em System ON dormindo, nPM1100 | ≈ 20 µA | 3,5 + 0,4 + a média das rajadas + ~10 + 0,8 µA |
| Dormindo (10 min parado) | BMA400 em low-power a 25 Hz com a interrupção de despertar, ADS1220 em power-down, rádio anunciando a cada 2 s | ≈ 15 µA | 0,85 + 0,4 + ~10 + 0,8 µA |
| Guardado | ship mode do nPM1100 | 0,46 µA | PS v1.5 |

O maior consumidor pedalando é a ponte, e a primeira versão desta tabela a contava ligada 15 % do tempo. Isso está errado: a 175 amostras/s em conversão contínua o conversor integra a conversão inteira (SBAS501D, 8.3.6 e 8.4.2.2), e a chave interna dele (PSW, 8.3.9) fecha no START e só abre no POWERDOWN; a ponte fica ligada enquanto se mede. Com a ponte de 1 kΩ isso dava 3,9 mA e 38 h, abaixo do requisito.

**Decidido pelo dono em 2026-09-27: extensômetros de classe transdutor de 5 kΩ.** A ponte cai de 3,0 para 0,6 mA, o total pedalando de 3,9 para 1,5 mA, e o requisito de 50 h passa a fechar com folga até numa célula de 100 mAh. O ruído não paga por isso: o ruído térmico de 5 kΩ numa banda de 10 Hz é 0,03 µV, contra os 0,26 µV RMS do próprio conversor com ganho 128 a 175 amostras/s. A decisão também é o que mantém o pod pequeno, porque as outras duas saídas ou não bastavam ou cresciam o aparelho:

| Saída recusada | Por quê |
|---|---|
| Modo duty-cycle do ADS1220 (MODE 01) com a excitação chaveada em volta de cada conversão | daria 1,8 mA, pior que os 1,5, e custa resolução: o filtro passa a ter o ruído do modo normal a 1 kSPS. Fica como reserva se o padrão de 5 kΩ não existir |
| Célula de 200 mAh | daria 51 h com a ponte de 1 kΩ, no limite, e **cresce o pod**, que já está acima do alvo em comprimento e altura ([Pod](#pod)) |

**O que falta confirmar, e é o risco desta decisão:** que exista **ponte completa de flexão numa peça só** em 5 kΩ. O catálogo da Micro-Measurements trata "padrões de ponte completa" e "padrões de alta resistência, de 350 Ω a 20 kΩ" como **duas famílias separadas**, o que já é sinal de que a interseção pode não existir; as páginas de padrão são carregadas por script e não abriram desta máquina em 2026-09-28, então isso se confirma com o fornecedor.

**A combinação que esta tabela não tinha, e que decide o produto:**

| Ponte | Modo | Ponte | ADS1220 | Rádio | **Total** | Com 81 mAh |
|---|---|---|---|---|---|---|
| 5 kΩ | contínuo | 0,600 | 0,585 | 0,300 | **1,50 mA** | **54 h** |
| **5 kΩ** | **duty-cycle 30 %** | **0,180** | **0,190** | 0,300 | **0,68 mA** | **119 h** |
| 1 kΩ | duty-cycle 30 % | 0,900 | 0,190 | 0,300 | 1,40 mA | 58 h |
| 1 kΩ | contínuo | 3,000 | 0,585 | 0,300 | 3,90 mA | 21 h |

**Decidido pelo dono em 2026-09-28: modo duty-cycle com a ponte de 5 kΩ.** A versão anterior desta página tinha os dois números do modo duty-cycle soltos — o conversor cai de 0,585 para 0,190 mA, e a ponte fica ligada 30 % do tempo porque o `PSW` que a alimenta abre junto (SBAS501D 8.3.9) — mas **nunca multiplicou os dois com a ponte de 5 kΩ**: a tabela só testava duty-cycle com 1 kΩ, de quando a ponte ainda era 1 kΩ. Juntos, eles cortam **55 % do consumo**, sem trocar uma peça e sem um milímetro a mais.

O preço é ruído: o filtro passa a ter o ruído do modo normal a 1 kSPS, cerca do dobro. Isso era proibitivo com o padrão de cisalhamento, que dá 0,31 mV, e é **folgado com o de flexão**, que dá 2,76 mV ([06](06-medicao-e-calibracao.md#cisalhamento-ou-flexão-o-padrão-especificado-está-errado)) — a relação sinal-ruído continua ordens de grandeza acima do necessário.

O modo está ligado no devicetree das duas placas (`duty-cycle;` no nó `ads1220`) e é o driver próprio que escreve `MODE = 01` no `CONFIG1`. **Não foi medido em bancada**: os 0,68 mA vêm da ficha do conversor, não de um amperímetro.

Só 350 Ω é que aperta: nem com duty-cycle fecha as 50 h na célula que cabe, e subir de capacidade engorda a célula, que é o que fixa a altura do pod — hoje 10,0 mm com 4,0 de célula. Nesse caso é melhor voltar aos quatro extensômetros separados de 5 kΩ e pagar o alinhamento.

O firmware já faz o que dá sem mudar peça: fora de `Active` e `Calibrating` o conversor fica em power-down e a excitação desligada, com uma rajada de 8 amostras a cada 10 s em `Idle` para o auto-zero e a saúde ([04](04-arquitetura-firmware.md#serviços)).

## Pinos do módulo

Regras do **nRF54L15** que valem aqui: o `SCL` de um TWIM e o `SCK` de um
SPIM precisam de pino com capacidade de clock, e a tabela desses pinos não
está neste repositório — os arquivos da própria Nordic no NCS estão, e é
deles que sai cada pino de barramento abaixo
([`../hardware_powermeter/09`](../hardware_powermeter/09-modulo-de-radio.md#o-mapa-de-pinos-do-projeto)).
Os blocos seriais seguem os portos: `spi00` no P2, e os blocos `20`, `21` e
`22` no P1 — e esses três são **o mesmo periférico** em três endereços, cada
um servindo como `i2c`, `spi` **ou** `uart`, um de cada vez.

O módulo é o **HOLYIOT-26001-A** e traz 30 dos 34 GPIO do SoC: `P0.00` a
`P0.04`, `P1.02` a `P1.15` e `P2.00` a `P2.10`. O projeto usa 20, e sobram
**nove** que existem de verdade nesta placa: `P0.00` a `P0.04`, `P1.03`,
`P2.00`, `P2.09` e `P2.10`, três deles com clock (`P0.03`, `P1.03`,
`P2.00`). `P0.05`, `P0.06` e `P1.00` estão livres **no SoC** e não têm pad
no módulo; `P1.01` e `P1.02` são os pads da antena NFC. O
`tools/fw/board_check.py` imprime as duas listas separadas desde
2026-09-28: antes ele juntava as duas e convidava a escolher um pino que
não dá para usar.

| Sinal | Pino do SoC | Pad do módulo | Vai para | No DK |
|---|---|---|---|---|
| `SPI00 SCK` | P2.01 (clock) | 10 | ADS1220 SCLK e BMA400 SCK | P3.03 (`spi22`) |
| `SPI00 MOSI` | P2.02 | 30 | ADS1220 DIN e BMA400 SDI | P3.00 |
| `SPI00 MISO` | P2.04 | 16 | ADS1220 DOUT/DRDY e BMA400 SDO | P3.01 |
| `ADC_CS` | P2.05 | 8 | ADS1220 CS | P3.02 |
| `ADC_DRDY` | P2.03 | 29 | ADS1220 DRDY (entrada, borda de descida) | P3.06 |
| `IMU_CS` | P2.07 | 28 | BMA400 CSB | P3.05 |
| `IMU_INT1` | P2.08 | 11 | BMA400 INT1 (entrada, ativo alto) | P3.04 |
| `I2C22 SCL` | P1.11 (clock) | 34 | TMP117 SCL, MAX17048 SCL | P1.11 |
| `I2C22 SDA` | P1.12 | 33 | TMP117 SDA, MAX17048 SDA | P1.12 |
| `EXC_EN` | P2.06 | 27 | TPS22916 ON (saída, alto liga a excitação) | P2.06 |
| `CHG_N` | P1.09 | 22 | nPM1100 CHG (dreno aberto, baixo carregando), pull-up | P1.09 |
| `ERR_N` | P1.08 | 12 | nPM1100 ERR (dreno aberto, baixo em erro), pull-up | P1.08 |
| `SHPACT` | P1.15 | 19 | nPM1100 SHPACT (alto por 200 ms com o cabo fora: ship mode; sai com o cabo) | P1.15 |
| `GAUGE_ALRT` | P1.07 | 13 | MAX17048 ALRT (dreno aberto), pull-up | P1.07 |
| `VBUS_SENSE` | P1.06 | 14 | divisor 1 M / 470 k no `VBUS`: é assim que o aparelho sabe que o cabo entrou | P1.06 |
| `LED_R`, `LED_G`, `LED_B` | P1.10, P1.13, P1.14 | 35, 21, 20 | LED RGB por resistor, ativo baixo | LEDs 0, 1 e 2 do DK |
| `UART20 TX`, `RX` | P1.04, P1.05 | 18, 17 | conector magnético, pelo TPD4E05U06: console, comandos e recuperação do MCUboot | VCOM0 do DK |
| `SWDIO`, `SWDCLK` | pads 4 e 5 | 4, 5 | conector magnético (100 Ω em série) e Tag-Connect TC2030 | |
| `NRESET` | pad 1 | 1 | só o Tag-Connect TC2030: o conector magnético tem seis contatos e não leva o reset | |

> [!IMPORTANT]
> **Não há USB.** O `usbhs` não existe no nRF54L15, e por isso não há pino
> `VBUS` no módulo: o pad 9 é o `P2.00`, um GPIO comum que os 5 V do cabo
> destruiriam. Os dois contatos do conector magnético que levavam `D+` e
> `D−` levam agora `TX` e `RX`, e eles **continuam chegando ao nPM1100**,
> que lê essas duas linhas sozinho para escolher entre 500 mA e 100 e não
> se importa com o que fala nelas.

Os aliases que o firmware usa são `bridge-adc`, `bridge-excitation`, `imu0`, `temp0`, `fuel-gauge0`, `charger-status`, `charger-error`, `ship-activate`, `led-r`, `led-g`, `led-b` e `watchdog0`, e um alias que não existe deixa aquele bloco fora. Ship mode: o nPM1100 entra com `SHPACT` alto por 200 ms sem cabo (PS v1.5, 3.5) e só sai com o cabo, porque `SHPHLD` fica só no pull-up e o pod não tem botão; é o estado de fábrica e de guarda longa (460 nA), pedido pelo comando `$SHIP`. O `$SLEEP` é outra coisa: o SoC em System OFF com o BMA400 acordando pelo `IMU_INT1`. Configuração por pino do nPM1100 (PS v1.5): `VOUTBSET0` e `VOUTBSET1` altos dão 3,0 V (tabela da seção 6.3.1); `VTERMSET` alto dá 4,2 V na opção padrão (tabela 12); `ISET` no `AVSS` deixa a detecção da porta decidir 100 ou 500 mA (tabela 10); `MODE` baixo é o modo automático do buck; sem termistor no pack, `NTC` leva 10 kΩ ao `AVSS` (6.2.5); `ICHG` de 6,8 kΩ dá cerca de 75 mA (equação da 6.2.4), 0,5 C de uma célula de 150 mAh.

## Placa

| Item | Valor |
|---|---|
| Camadas | 4: `F.Cu`, `In1.Cu` terra, `In2.Cu` alimentação, `B.Cu` |
| Espessura | 0,8 mm |
| Contorno | derivado das peças e do pod; alvo 48 × 16 mm |
| Antena | **cerâmica**, na ponta do módulo virada para a borda da placa. O guia de montagem do fabricante classifica a antena passando para fora da borda como a melhor posição, o canto como boa e o meio da placa como a pior, e pede que ela fique **sem plano de terra embaixo**. Não há mais recorte vazado na placa: aquilo era o que a antena de traço do ME54BS13 pedia ([09](../hardware_powermeter/09-modulo-de-radio.md#a-antena-manda-no-layout)) |
| Analógico | ponte e ADS1220 num canto, longe do buck e do módulo; filtro RC nas entradas e na referência como o datasheet do ADS1220 pede; retorno de terra da ponte direto ao AVSS |
| Montagem | tudo de um lado, para o pod ser raso; o módulo é a peça mais alta (2,4 mm) |

### Orientação do acelerômetro

Este é um requisito **da placa sobre o firmware**. Como o pod é colado na face interna do braço, o plano da placa é o plano de rotação do pedivela, e daí saem três exigências:

| Papel | Onde tem de apontar | Por quê |
|---|---|---|
| Lateral | normal à placa, para fora da face que leva o ponto do pino 1 | é o eixo ao longo do eixo central; lê perto de zero sempre, e é o que sobra |
| Radial | ao longo do braço, positivo **para fora**, do eixo central para o pedal | é o radial de [06](06-medicao-e-calibracao.md#ângulo-e-cadência), onde entra o termo centrípeto `ω²r` |
| Tangencial | atravessado ao braço, no plano de rotação | os cruzamentos de zero dele dão `ω` |

A convenção de sinais é a da seção 8.2 da ficha BST-BMA400-DS000-14: X e Y no plano do encapsulamento, Z saindo da face de cima, e aceleração na direção indicada dá leitura positiva.

**Medido em 2026-09-27**, lendo a tabela de orientação da ficha contra o canto do pino 1 do footprint (`Package_LGA:LGA-12_2x2mm_P0.5mm`) e a rotação do `U401` na placa: o **Y** do encapsulamento fica ao longo do braço e o **X** atravessado, e o `+Y` aponta para a ponta da placa que fica do lado do eixo central. Daí os valores do firmware: `CONFIG_PM_IMU_AXIS_RADIAL = 1` (Y), `CONFIG_PM_IMU_AXIS_TANGENTIAL = 0` (X) e `CONFIG_PM_IMU_RADIAL_SIGN = -1`, que é o que faz o radial crescer para fora. Antes dessa medida os três eram palpite, e o palpite estava **invertido**.

Os dois lados não podem se mover sozinhos: a regra `IM1` do dry run da placa mede a orientação do `U401` e reprova enquanto a placa e esses símbolos discordarem. Trocar radial por tangencial mete o termo centrípeto dentro da cadência e a potência sai errada sem nenhum sinal de erro, e é por isso que isto é verificação automática e não comentário. É a mesma regra da orientação de modelo STEP: mede-se no desenho do fabricante, nunca se conclui por intuição.

## Pod

O pod é desenhado em volta da placa e da célula pela mesma ideia do case do ciclocomputador: um gerador e um dry run próprio, em [`hardware_powermeter/07-pod.md`](../hardware_powermeter/07-pod.md). A célula fica **sob** a placa: ao lado dela o comprimento cresce muito mais do que a altura economiza.

O primeiro desenho fechou em 65,4 × 19,4 × 10,5 mm, acima do alvo em comprimento e altura, e o caminho de volta às três medidas sai das decisões de 2026-09-27:

| Onde | De | Para | Como |
|---|---|---|---|
| Espessura da célula | 5,0 mm | ~~2,5 mm~~ ~~4,0 mm~~ **5,0 mm** | **esta linha estava errada e foi refeita duas vezes**: em 2026-09-28, porque em 23 × 11 × 2,5 uma LiPo de bolsa vale cerca de 49 mAh e não 100; e em 2026-09-30, quando a célula saiu de baixo da placa e passou a ficar AO LADO dela, o que mudou o envelope de 23 × 11 × 4,0 para **15 × 14 × 5,0 (≥ 81 mAh)**. A 0,68 mA ela dá **119 h** |
| Teto sobre a placa | 3,2 mm | ~~2,7~~ **3,2 mm** | quem obriga os 3,2 é o conector da célula. Ele virou dois furos de solda em 2026-09-26 e o teto caiu para 2,7; em 2026-10-01 o dono o trouxe de volta — a célula que se compra já vem com plugue — e o teto voltou a 3,2 ([06](../hardware_powermeter/06-conectores-e-pontos-de-teste.md#j102--célula)) |
| **Altura total** | **10,5 mm** | **10,0 mm** | com a célula de 4,0 mm de verdade, é o alvo, exatamente |
| Comprimento da placa | 60 mm | cerca de 55 mm | passivos baixos na face de trás **fora da sombra da célula**: ela cobre 23 a 25 mm dos 60, e os outros 35 ficam sobre o fundo do pod. Um passivo 0402 pede 0,6 mm de vão, contra os 2,5 da célula, então não custa altura |
| **Comprimento total** | **65,4 mm** | **cerca de 60 mm** | a placa menor, mais as paredes e a folga; o canal dos fios da célula na ponta deixa de existir, porque os fios saem pelo rebaixo do fundo |

A largura já está dentro, e a troca do módulo em 2026-09-28 a levou de 19,4 para 19,0. O custo assumido é montagem nas duas faces, mais cara de fabricar, e a face de trás deixa de ser plana: ela passa a ser plana **sob a sombra da célula**, e é assim que as regras do dry run medem.

### A célula saiu de baixo da placa (2026-09-30)

Decisão do dono: **a célula passa a ficar ao lado da placa**, não sob ela, para o aparelho ficar mais baixo. Ela sai da pilha de altura e entra na de comprimento, e a tabela acima deixa de valer nas três linhas que dependiam disso.

| | Antes (célula embaixo) | Agora (célula ao lado) |
|---|---|---|
| Pod | 55,7 × 19,0 × **10,0** | 73,5 × **20,0** × **7,7** |
| Pilha da altura | fundo 1,0 + célula 4,0 + ar 0,5 + placa 0,8 + teto 2,7 + tampa 1,0 | fundo 1,0 + **ar do verso 1,5** + placa 0,8 + teto 2,7 + tampa 1,0 |
| Célula | 23 × 11 × 4,0 = 1.012 mm³ ≈ 78 mAh | **15 × 14 × 5,0 = 1.050 mm³ ≈ 81 mAh** |
| Face de trás | plana sob a sombra da célula, 1,0 mm fora dela | **1,5 mm de ponta a ponta**: não há mais sombra |
| `cola + pod` contra a folga do quadro | 10,5 contra 10,0 ✗ | **7,5 contra 10,0 ✓** |

A célula muda de forma porque muda o que ela custa: embaixo, ela tinha de ser comprida e estreita para caber entre os ressaltos; ao lado, quanto mais larga e mais grossa, menos comprimento toma. Os 5,0 mm de espessura são de graça — a pilha da placa já reserva 5,0 no mesmo espaço.

**O que não fechou:** o pod tem 21,0 mm de largura e a face interna de um braço da classe tem 20,0, então ele sobra 0,5 mm de cada lado. A área de colagem cabe, o relevo livra a concordância e a folga do quadro passa; o que excede é só a silhueta. Fechar isso pede placa de 15 mm em vez de 16 (que custa roteamento) ou aceitar a sobra. A `PD17` reprova com o número até você decidir.

## Conector magnético

Seis pinos pogo, ímã com polaridade, passo de 2,0 a 2,5 mm, 1 A por pino, banho de ouro, face plana vedada por junta e envasada por trás. O cabo termina em USB-A (5 V, GND, D+, D−) e numa saída SWD de 10 vias (Cortex Debug) para o J-Link. Proteção: TPD4E05U06 nos quatro sinais, 100 Ω em série no SWD, e o VBUS entra no nPM1100, que é entrada; nada sai do pod pelos pinos sem cabo. O fornecedor é escolhido com o desenho do footprint, que entra na cadeia de CAD como as outras peças, com o corpo 3D medido.

**Arranjo dos contatos: duas fileiras de três, não fila única.** Seis contatos a 2,5 mm em fila ocupam 12,5 mm num comprimento de placa que agora é de 33; em 2 × 3 a mesma peça cabe em cerca de 5 × 7,5 mm. Como nenhum fornecedor foi escolhido ainda, o arranjo é escolha do projeto e vira requisito de compra.

**Altura mínima do corpo: 3,2 mm**, requisito que saiu do desenho do pod e não do circuito. O conector atravessa a tampa e a face dele fica num poço, abaixo do topo, para não bater na perna do ciclista; se o corpo for mais baixo que a soma do teto com a espessura da tampa, a face fica abaixo da superfície de baixo dela e a cabeça magnética do cabo não alcança. A regra `PD3` do dry run do pod mede as três condições juntas ([`hardware_powermeter/07`](../hardware_powermeter/07-pod.md#o-conector-magnético-na-tampa)). Leve esse número junto do passo e da corrente na hora de escolher a peça.

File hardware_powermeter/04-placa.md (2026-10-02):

# Placa

O contorno, as camadas, onde cada bloco fica e onde nada pode ficar. Fecha
o que as [folhas do esquemático](02-esquematico.md) deixam em aberto por
natureza: um esquemático diz o que se liga a quê, e é o layout que decide
se a antena enxerga o ar, se o ruído do buck cai dentro da ponte e se a
placa cabe no pod. Tudo aqui sai de [`cad/`](cad/README.md); o que foi
medido está em [10](10-dry-run-2026-09-28.md), e a primeira medida completa
em [08](08-dry-run-2026-09-27.md).

**Nesta página:** [O contorno](#o-contorno) · [Camadas](#camadas) · [Posicionamento](#posicionamento) · [Zonas proibidas](#zonas-proibidas) · [O land pattern do módulo](#o-land-pattern-do-módulo) · [A orientação do acelerômetro](#a-orientação-do-acelerômetro) · [Roteamento](#roteamento) · [O que falta](#o-que-falta) · [Verificação](#verificação)

> [!WARNING]
> **Não existe placa física e nada foi fabricado nem medido.** Não há
> gerber, não há pilha de camadas de fabricante e ninguém encostou uma
> ponta de prova em nada. O que existe é o projeto em KiCad, em
> [`cad/`](cad/README.md): as 58 peças posicionadas, os três planos de
> cobre e as trilhas.
>
> **A placa está roteada com 0 erros de DRC**, e mesmo assim **não pode ser
> fabricada**: **2 ligações de sinal continuam sem cobre** (`CHG_N` e `VBAT`)
> e 10 dos 19 capacitores de desacoplamento estão além do limite da ficha
> ([o que falta](#o-que-falta)).
>
> **E ela voltou a ser reproduzível pelo gerador em 2026-10-01.** Antes disso
> não era: a reserva do furo de fixação invadia o courtyard do conector
> magnético, o colocador não conseguia mais pôr o `J101` em lugar nenhum, e a
> placa publicada vinha de um estado anterior do código. Ninguém soube porque
> a verificação rodava sobre o **arquivo** e nunca sobre o gerador —
> `make_pcb.py --conferir` existe por causa disso.

## O contorno

| Item | Valor |
|---|---|
| Tamanho | **50 × 16 mm** |
| Espessura | 0,8 mm |
| Raio dos cantos | 1,5 mm |
| Furo de fixação | **um**, M1,6 passante em **(30,5; 8,0)**, Ø 2,2 mm, com reserva de 1,4 mm de raio; o outro extremo da placa é preso pelos ressaltos ([07](07-pod.md)). Ele estava em y = 7,0 até 2026-10-01, onde a reserva dele invadia o courtyard do conector magnético em 2,65 × 0,45 mm e **o colocador não conseguia mais pôr o `J101` em lugar nenhum** — a placa publicada vinha de um estado anterior do código. Na linha de centro ele livra o conector por 0,55 e prende melhor |
| Recorte | **nenhum**: a antena do módulo é cerâmica e pede zona livre, não placa vazada |

O alvo de [`docs/02`](../docs/02-hardware.md#placa) era 48 × 16. A placa é
menor que o alvo, e quem a encolheu foi a **troca do módulo de rádio**
([09](09-modulo-de-radio.md)): o ME54BS13 ocupava 12,0 × 16,5 mm, o
HOLYIOT-26001-A ocupa 10,0 × 12,5, e aquele módulo sozinho era 26 % da área
da placa — mais que as 37 peças pequenas somadas. Nenhuma outra alavanca de
tamanho chega perto: passar os passivos de 0402 para 0201 devolveria menos
de um terço disso e custaria montagem.

**A largura é o ganho que interessa.** Ela é o limite do pod, não uma
escolha: a face interna do braço do pedivela dá 20 mm de envelope, menos
duas paredes e duas folgas ([07](07-pod.md#o-envelope)), e quem punha o
piso era a largura do módulo. Com 10 mm no lugar de 12 a placa vai de 16
para **14 mm**, e o pod de 19,4 para **17,4** — abaixo da faixa inteira da
classe de referência (18 a 22 mm).

**O comprimento não saiu de uma conta**, e sim de rodar o colocador e o
roteador em um comprimento atrás do outro (`PMETER_W=48 python
make_pcb.py`). O que decide não é área livre e sim **quantos lugares aceitam
uma via**: a fuga de um pad de passo fino precisa de uma. Em 47 mm as 58
peças assentam, `RF4` passa (a antena cerâmica encosta na borda) e o
roteador fecha; encurtar mais tira sítios de via antes de tirar área.

## Camadas

Empilhamento assimétrico de quatro camadas, o mesmo do ciclocomputador:

| Camada | Uso | Dielétrico abaixo |
|---|---|---|
| `F.Cu` | sinais e todas as peças | 0,10 mm |
| `In1.Cu` | **terra contínuo** | 0,50 mm |
| `In2.Cu` | alimentação e sinais que atravessam | 0,10 mm |
| `B.Cu` | sinais; nenhuma peça, só pads de teste | — |

`F.Cu` e `B.Cu` também levam despejo de terra, costurado à `In1.Cu` por
vias na borda e por uma malha de 4 mm ([`cad/route.py`](cad/route.py)).

Classes de rede ([`cad/make_pro.py`](cad/make_pro.py)): isolamento de
0,127 mm em todas (o mínimo do fabricante), trilha de 0,15 mm para sinal e
0,40 para alimentação, via de 0,45/0,25 mm e de 0,60/0,30 na classe de
alimentação.

## Posicionamento

```mermaid
flowchart LR
    E["0 a 14<br/>ENERGIA<br/>nPM1100 · indutor<br/>medidor · J102"]
    C["14 a 34<br/>conector magnético na borda de cima<br/>Tag-Connect e LED · ADS1220 e filtro<br/>furos da ponte na borda de baixo · sensores<br/>furo M1,6 em (30,5; 8,0)"]
    M["34 a 47<br/>MÓDULO<br/>antena cerâmica encostando<br/>na borda direita"]
    E --- C --- M
```

O que decide cada limite:

- **o módulo** fica no extremo direito com a antena virada para fora da
  borda. O guia de montagem do fabricante classifica a antena passando
  para fora da borda da placa como a **melhor** posição, o canto como boa e
  o meio da placa como a pior, e pede a região sem plano de terra
  ([09](09-modulo-de-radio.md#a-antena-manda-no-layout)). Não há mais
  recorte vazado: aquilo era o que a antena de traço do módulo antigo
  pedia;
- **o bloco de energia** acaba 20 mm antes do módulo, que é a distância que
  a regra de isolamento de interferência pede de uma fonte chaveada ou de
  um indutor de potência. É esse número, e não a estética, que empurra o
  buck para o outro extremo;
- **o conector magnético** fica deitado na borda de cima, no meio, com os
  pinos para a tampa do pod;
- **os furos da ponte** ficam na borda de baixo, sob o conversor: os fios
  sobem do braço por um rasgo no fundo do pod, direto sob eles
  ([07](07-pod.md#os-fios-da-ponte));
- **o canto analógico** (ADS1220, filtro, chave da excitação) fica entre
  os dois, o mais longe que a placa permite do buck e do módulo.

Quase tudo numa face só. A face de trás leva os sete pontos de teste, que
são pads, e onze peças que não precisam ser alcançadas: o desacoplamento do
módulo com os resistores de barramento (`C201` a `C203`, `FB201`, `R204`,
`R205`), os dois chips baixos da ponta direita (`U302` e `U402`) e o
desacoplamento deles (`C307`, `C308`, `C403`). Isso é possível porque a
célula cobre só 23 dos 47 mm: passada ela o fundo do pod desce, e a regra
`PD4` mede o ar sob **cada** peça em vez de proibir todas
([07](07-pod.md#o-que-segura-cada-peça)).

## Zonas proibidas

| Zona | O que é | Fonte |
|---|---|---|
| `KEEPOUT_ANTENA_MODULO` | 4,3 mm da borda direita: sem cobre, sem componente, sem metal, sem plano de terra | guia de montagem do HOLYIOT-26001-A ([09](09-modulo-de-radio.md#a-antena-manda-no-layout)) |
| `SOMBRA_CELULA_MAX_0-0MM` | a sombra da célula na face de trás: nenhuma peça pode ficar sob ela | derivada das cotas da própria célula em `make_dxf` |
| `SOMBRA_TAMPA_MAX_3-2MM` | teto de 3,2 mm sobre a face da frente | [07](07-pod.md#a-pilha-de-alturas) |

**O recorte vazado saiu.** A antena de traço do módulo antigo pedia a placa
aberta sob ela; a cerâmica do HOLYIOT pede o contrário — corpo dielétrico
sobre substrato, com a região livre de cobre e **encostando numa borda**.
A regra `RF4` do dry run mudou junto: ela mede se a antena está dentro da
zona livre **e** se toca uma borda da placa, e não mais se existe um furo
vazado.

O teto é o de `make_dxf.TETO_TAMPA` e o nome da zona sai dele, então os dois
nunca divergem. Quem o fixa é a peça mais alta que fica **sob a tampa**, e
desde 2026-10-01 essa peça é o **conector da célula**: o JST SH tem 2,90 mm e
o teto é **3,20**. Ele foi 2,7 — o módulo, com 2,40 mais 0,3 de ar — enquanto
a célula chegava soldada em dois furos, e voltou a 3,2 quando o dono decidiu
que ela entra por conector
([06](06-conectores-e-pontos-de-teste.md#j102--célula)). A regra `PD2` do dry
run do pod é quem mede isso a cada execução, e o único que atravessa a tampa é
o conector magnético (`make_dxf.ATRAVESSA_TAMPA`).

## O land pattern do módulo

> [!WARNING]
> **Do HOLYIOT-26001-A não existe ficha em PDF, nem land pattern oficial,
> nem desenho de terceiros.** O que existe é o desenho mecânico do anúncio
> do fabricante, fotografado pelo dono em 2026-09-28. O footprint é
> desenhado aqui a partir dele, e **não tem conferência independente**.
> Com o módulo antigo havia: um desenho comunitário do mesmo módulo batia
> pad a pad com o nosso, desvio máximo 0,000 mm. Aqui não há com o que
> comparar, e a única saída é medir uma peça real quando ela chegar.

O que o desenho dá, e o que o gerador
[`cad/footprints.py`](cad/footprints.py) reproduz:

| | Valor |
|---|---|
| Corpo | 10,0 × 12,5 mm |
| Ilhas | **36**, todas meio-furo (castelado), passo **1,2 mm** |
| Nas bordas esquerda e direita | 7 fileiras × 2 ilhas de cada lado: a externa em \|x\| = 4,75 mm, 1,5 × 0,6; a interna em \|x\| = 2,5 mm, 1,0 × 0,8 |
| Na borda de baixo | 8 ilhas de 0,6 × 1,0, em \|x\| = 0,6 / 1,8 / 3,0 / 4,2 |
| Pé de solda | **0,5 mm** para fora do corpo, só nas ilhas de borda |
| Antena | cerâmica, a faixa de 3,8 mm na ponta de cima (`Dwgs.User` no footprint) |

A regra `ME7` de [`cad/dry_run_pcb.py`](cad/dry_run_pcb.py) foi refeita em
2026-09-28 junto com o módulo. Ela **não pode mais** comparar com um
terceiro, então mede a coerência interna do desenho, que é o que ainda pega
erro de gerador: uma ilha por pino da tabela `PADS_HOLYIOT` do esquemático
(36 para 36), nenhum nome repetido, o corpo do `F.Fab` igual ao de
`footprints.CORPO` — que é o corpo que o 3D e o pod usam —, nenhuma ilha
saindo mais que os 0,5 mm de pé de solda, e passo constante em cada
fileira. **Medido em 2026-09-28: passa, com a saída máxima em exatamente
0,500 mm.** E a regra diz, em toda execução, que isso não é conferência
independente.

> O primeiro desenho da regra media o corpo pelo centro do envelope das
> ilhas, e isso estava errado: as ilhas não são simétricas em `y` (só a
> borda de baixo tem fileira), então o corpo saía 1,9 mm fora do lugar e
> toda ilha de baixo parecia estar escapando da peça. O corpo é o retângulo
> do `F.Fab`.

**O espelhamento** do mapa continua por conferir num módulo real: é a mesma
pendência do módulo antigo, e ela não some porque a peça mudou.

## A orientação do acelerômetro

O firmware escolhe qual eixo do BMA400 é o radial e qual é o tangencial
por dois símbolos Kconfig. Trocar os dois mete o termo centrípeto dentro
da cadência e **a potência sai errada sem nenhum sinal de erro**. O fato
que decide isso é físico e está aqui, medido.

**O que a ficha diz** (Bosch BST-BMA400-DS000-14, 8.2, página 112, na
tabela de orientação): numa **vista de cima**, com o ponto do pino 1 no
canto **superior esquerdo**, o `+X` do sensor aponta para **cima** da
página e o `+Y` para a **esquerda**; o `+Z` sai da face que leva o ponto.

**O que o footprint dá**: no `Package_LGA:LGA-12_2x2mm_P0.5mm` do KiCad o
pad 1 fica em (−0,762; −0,750), isto é, no canto **superior esquerdo** do
desenho — o mesmo canto da ficha.

**Como o U401 está posto**: rotação 0°, na face da frente.

**O resultado, medido pela regra `IM1`:**

| Eixo do sensor | Direção na placa | Papel no pedivela |
|---|---|---|
| `X` | −y (para a borda de cima) | **tangencial** |
| `Y` | −x (para a ponta esquerda) | **radial** |
| `Z` | saindo da face da frente | lateral, ao longo do eixo do pedivela |

O eixo longo da placa (x) é o que corre **ao longo do braço**, e a ponta
direita — a do módulo e da antena — é a que aponta para **fora**, para o
pedal: a antena fica o mais longe possível do eixo central e do quadro.
Logo o `+Y` do sensor, que aponta para a ponta esquerda, aponta **para o
eixo central**, para dentro.

> [!IMPORTANT]
> **O mapeamento está trocado em relação ao que o firmware supõe.** O
> firmware tem `PM_IMU_AXIS_RADIAL = X` e `PM_IMU_AXIS_TANGENTIAL = Y`, e
> a medida dá o contrário. Há duas saídas, e as duas fecham:
>
> 1. **girar o `U401` 90°** na placa, e aí o `X` do sensor passa a correr
>    ao longo do braço e o Kconfig fica como está;
> 2. **trocar os dois símbolos** no firmware, e então o sinal de
>    `PM_IMU_RADIAL_SIGN` tem de ser o que aponta para fora: como o `+Y`
>    aponta para o eixo central, o radial positivo é `−Y`.
>
> A regra `IM1` de [`cad/dry_run_pcb.py`](cad/dry_run_pcb.py) refaz essa
> medida a cada execução, reprova enquanto os dois lados não concordarem,
> e **falha dizendo que não pôde medir** se a ficha não estiver em
> `datasheets/`.

## Roteamento

| Medida | Valor |
|---|---|
| Segmentos | **1.383** |
| Vias | **232** |
| Ligações fechadas | **88** |
| Itens desconectados no DRC completo | **21** |
| **Erros de DRC** | **0** |
| Avisos de DRC | todos de registro de biblioteca |

**Estes números são de 2026-09-29 e não são comparáveis com os de 28.** Na
placa de 28 o módulo de rádio estava **sem uma única ligação** (as ilhas
dele saíram nomeadas pelo sinal em vez de numeradas, e nenhuma rede as
achava), então um quarto das ligações da placa não existia. Com o módulo
ligado o roteador tem 25 ligações a mais para fazer, e os desconectados
sobem de 14 para 30 — o 14 era favorável por omissão.

Das que faltam, **22 das 49 que o roteador não fechou são vias de costura
do plano de terra**, que o plano resolve. As de sinal se agrupam em dois
lugares, e os dois são **fuga de ilha de passo fino**: os pinos do nPM1100
(um QFN de 0,5 mm com nove redes presas) e os do módulo. Não é falta de
área: crescer a placa para 50 ou 52 mm foi medido e dá 33 desconectados
em vez de 30.

O roteador é o do ciclocomputador e levou três correções medidas nesta
placa, que [`cad/README.md`](cad/README.md#o-que-mudou-em-relação-ao-ciclocomputador)
detalha: a ordem das ligações passa a crescer do pino mais próximo; o
pescoço dentro do campo de pads deixou de pedir folga que um passo de
0,5 mm não tem; e a isolação reservada em volta de um pad, de uma trilha e
de uma via passou a ser a da trilha **mais larga** que pode passar ali, e
não a da mais estreita. A última troca 17 ligações por **zero erro de
DRC**, e foi escolhida assim de propósito: uma violação de isolamento é um
curto na placa fabricada, e uma ligação sem trilha é uma falta visível.

## O que falta

Em ordem de gravidade:

0. **Duas ligações de sinal sem cobre: `CHG_N` e `VBAT`.** A placa rotea com
   0 erros de DRC e para sempre nessas duas. O que foi **medido** em
   2026-10-02, para que a próxima tentativa não repita:

   | Hipótese | Como foi testada | Resultado |
   |---|---|---|
   | Falta de esforço do roteador | 100 e 500 passagens, ~40 passadas | **refutada**: sempre 2 em aberto |
   | Posição de peça | furo em (30,5; 7,0), (30,5; 8,0) e (34,0; 12,0); `J102` em y 3,4 e 8,0 | **refutada**: (34; 12) piorou para 12 erros e 3 em aberto; o resto empatou |
   | **Fuga de pad** — a ponta não consegue mudar de camada | `medir_fuga.py`: varre um anel em volta de cada pad e pergunta ao `route.via_cabe_aqui` | **refutada**: os 13 pads têm lugar de via, vários a 0,5 mm |
   | Folga inflada no DSN apertando os corredores | as regras sem via baixadas de 115 para os 88,9 reais | **refutada** para o roteamento (mas a correção fica: pedir 115 entre duas trilhas era errado) |

   O que sobrou e ainda não foi medido: **se existe corredor livre** entre as
   duas ilhas de cada rede, em alguma camada. `CHG_N` precisa ir de (20,5; 9,5)
   no verso até o pino do módulo em (46,0; 12,8) na frente — 25 mm. O
   `fechar_ultimas.py` não serve para isso: o raio de busca dele é 5 mm, ele é
   a ferramenta do último milímetro.

1. **10 de 19 capacitores de desacoplamento além do limite da ficha**, o
   pior a 7,7 mm de um pino que pede 2. O colocador foi instrumentado por
   dentro e **decide certo**: o melhor lugar **livre** está mesmo a 2,90 mm
   do pino do `C302` e a 6,25 do `C402`. Quem come esse raio é o
   empilhamento de courtyards — o do próprio circuito integrado, o do 0402
   e a folga entre peças —, e num VQFN de 3,5 mm com um 0402 na mesma face
   os 2 mm da ficha podem simplesmente não caber. A saída clássica é o
   desacoplamento na **face de trás direto sob o chip**, onde o laço é
   pad → via → pad; é decisão do dono. O `AN1` e o `AN2` têm a mesma raiz.
2. **3 ligações de sinal sem cobre** — `I2C_SCL`, `SPI_MOSI` e `SPI_SCK` —,
   todas no mesmo trecho entre o conversor e o módulo. A placa não é
   fabricável assim.
3. **9 trechos da serial dentro do retângulo sem plano do nó de
   chaveamento** (`US1`). O conflito é estrutural: a serial tem de chegar
   ao nPM1100, que lê `D+`/`D−` para escolher a corrente de carga, e esses
   pinos ficam ao lado do próprio nó. A 115200 baud o risco é pequeno, mas
   a regra relata em vez de esconder.

## Verificação

```
python hardware_powermeter/cad/make_dxf.py
python hardware_powermeter/cad/check_dxf.py
python hardware_powermeter/cad/make_pcb.py
python hardware_powermeter/cad/route.py
"D:/KiCAD/bin/python.exe" hardware_powermeter/cad/fill_zones.py
python hardware_powermeter/cad/make_pro.py
python hardware_powermeter/cad/check_pcb.py --como-esta
python hardware_powermeter/cad/dry_run_pcb.py
```

> [!CAUTION]
> **O KiCad reescreve o `pmeter.kicad_pro` com os padrões dele** sempre que
> o `pcbnew` ou o `kicad-cli` abre o projeto. Rodar o DRC sem regerar o
> arquivo antes mede a placa contra isolamento de 0,2 mm, via mínima de
> 0,5 e furo mínimo de 0,3, que não são as regras deste projeto: em
> 2026-09-27 isso deu 722 erros, dos quais 390 eram as 195 vias reprovadas
> duas vezes. `python make_pro.py` antes de cada DRC.

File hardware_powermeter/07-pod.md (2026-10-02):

# Pod

O invólucro colado na face interna do braço esquerdo do pedivela: o que
ele segura, como, e o que ainda depende de medir o pedivela do dono. É
desenhado **em volta da placa real** por [`pod/make_pod.py`](pod/make_pod.py)
e medido por [`pod/dry_run_pod.py`](pod/dry_run_pod.py), pela mesma ideia
do case do ciclocomputador: um gerador, um dry run, e nenhum número que
não venha de um documento ou de uma medida.

**Nesta página:** [O envelope](#o-envelope) · [A pilha de alturas](#a-pilha-de-alturas) · [O que segura cada peça](#o-que-segura-cada-peça) · [Os fios da ponte](#os-fios-da-ponte) · [A célula e o conector dela](#a-célula-o-conector-dela-e-o-corte-dos-cabos) · [O conector magnético na tampa](#o-conector-magnético-na-tampa) · [Vedação e envase](#vedação-e-envase) · [Massa](#massa) · [As regras do dry run](#as-regras-do-dry-run) · [Medir o sólido, não a constante](#medir-o-sólido-não-a-constante) · [Lugares reservados](#lugares-reservados)

> [!WARNING]
> **Nada foi impresso, colado nem pesado.** Toda medida abaixo sai do
> gerador ou de uma conta feita aqui, e a massa é **estimativa por volume
> e densidade**, não pesagem. As medidas do pedivela são lugares
> reservados: ninguém mediu o braço.

## O envelope

| Medida | Alvo de [`docs/02`](../docs/02-hardware.md#requisitos) | O que o desenho dá | Situação |
|---|---|---|---|
| Comprimento | **38 mm** | **73,5 mm** | **fora**: a placa tem 50 mm ([04](04-placa.md#o-contorno)) e a célula ficou **ao lado** dela |
| Largura | 20 mm | **20,0 mm** | **dentro, exato**: placa de 16 mais 0,5 de folga e 1,5 de parede de cada lado |
| Altura | 10 mm | **7,7 mm** | dentro, com 2,3 de folga |

As duas medidas que não fecham são consequência direta de duas decisões já
tomadas, e nenhuma delas é um defeito de geometria:

- **O comprimento** é a placa mais a célula ao lado. A decisão do dono em
  2026-09-30 foi tirar a célula de baixo da placa, o que levou a altura de
  10,0 para 7,2 e o comprimento para cá. Encurtar o pod pede encurtar a
  placa ou empilhar a célula de novo.
- **A largura** é a placa de 16 mm mais 0,5 de folga e 2,0 de parede de cada
  lado. A parede é 2,0 porque o sulco do anel O precisa de 1,05 mais 0,5 de
  terra de cada lado (`PD13`); com 1,2 de parede não há vedação por anel O.

O alvo de `docs/02` foi corrigido em 2026-10-01: ele é **38 × 20 × 10**
desde 2026-09-27, e o gerador ainda media contra os 60 que o próprio
documento diz que o projeto deixou de perseguir. A regra `PD10` passou a
medir contra o número certo, e reprova.

### O pod não cola pela face inteira

A face interna do braço não é plana de ponta a ponta: ela tem uma
concordância de cerca de 2,5 mm de cada lado, então dos 20 mm de largura da
classe só **15** são planos. Um pod de 19,0 colado por baixo inteiro
apoiaria nesses raios dos dois lados — cola grossa nas bordas, fina no meio,
e a junta descola de fora para dentro. Por isso o fundo tem uma **base de
colagem de 15 mm** e sobe 1,0 mm fora dela: o pod continua com 19,0 de
largura, porque a placa precisa deles, e a cola só toca metal plano. A regra
`PD17` mede isso.

> [!IMPORTANT]
> **O tamanho do pod e o orçamento de consumo são a mesma decisão, e a
> saída mais óbvia do consumo é a pior para o pod.** O
> [orçamento de consumo](../docs/02-hardware.md#orçamento-de-consumo)
> deixa três saídas para fechar as 50 h pedalando, e elas não custam o
> mesmo aqui:
>
> | Saída do consumo | Efeito no pod |
> |---|---|
> | Extensômetros de **5 kΩ** | **nenhum**: a ponte cai de 3,0 para 0,6 mA e o total pedalando de 3,9 para cerca de 1,5 mA sem tocar na célula |
> | Modo **duty-cycle** do ADS1220 | nenhum: é firmware. Junto com a ponte de 5 kΩ o total cai para **0,68 mA**, e é essa combinação que faz a célula de 81 mAh valer 119 h |
> | Célula de **200 mAh** | **piora**: a célula fica sob a placa, então cresce na altura, que é o número que fechou mais apertado, e provavelmente no comprimento |
>
> Com 0,68 mA a célula de 200 mAh deixou de ser necessária, e é por isso que
> ela não está no desenho.

O que ainda governa cada medida:

- **o comprimento** segue a placa, e leva junto a sala dos dois parafusos
  de fechamento: eles custam 5,4 mm porque a placa toma o meio e cada ponta
  tem de abrigar o seu ressalto;
- **a altura** é a pilha abaixo, e fecha em 10,0 com a célula de 4,0 mm
  **sob** a placa. Pôr a célula **ao lado** estouraria o comprimento: uma de
  23 × 11 ao lado de uma placa de 47 × 14 daria 72 mm de comprimento ou
  27 de largura, os dois bem piores;
- **a largura** é o módulo de rádio mais as paredes. O módulo põe o piso da
  largura da placa, e foi por isso que trocá-lo (12,0 → 10,0 mm de largura)
  levou o pod de 19,4 para 19,0 **mesmo com a parede engordando de 1,2 para
  2,0** por causa do sulco do anel O.
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

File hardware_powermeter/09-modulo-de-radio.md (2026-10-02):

# Módulo de rádio

O **HOLYIOT-26001-A**: o que ele tem, o que ele custa e por que o projeto
troca o ME54BS13 por ele. A pinagem e as cotas foram lidas no desenho
mecânico do fabricante (fotos do anúncio, enviadas pelo dono em 2026-09-28);
tudo o que é sobre o SoC foi conferido no **NCS v3.3.0 instalado**, arquivo
por arquivo, e não de memória.

**Nesta página:** [Por que trocar](#por-que-trocar) · [O que o SoC muda](#o-que-o-soc-muda) · [Pinagem](#pinagem) · [Mecânica](#mecânica) · [A antena manda no layout](#a-antena-manda-no-layout) · [O mapa de pinos do projeto](#o-mapa-de-pinos-do-projeto) · [O que falta confirmar](#o-que-falta-confirmar)

> [!WARNING]
> **Nenhum módulo foi comprado, soldado ou medido.** As cotas vêm do desenho
> mecânico do anúncio, não de uma peça na bancada nem de uma ficha em PDF. O
> footprint gerado a partir delas é provisório até alguém medir uma peça
> real, e a altura do corpo **não consta em lugar nenhum**.

## Por que trocar

O motivo é um só e foi medido: o módulo era **26 % da área da placa numa
peça só**, mais que as 37 peças pequenas somadas. Passivo não move esse
número; o módulo move.

| | ME54BS13 (nRF54LM20A) | HOLYIOT-26001-A (nRF54L15) |
|---|---|---|
| Corpo | 12,0 × 16,5 mm | **10,0 × 12,5 mm** |
| Courtyard | 212,5 mm² (26 % da placa) | ~136 mm² |
| Pinos | 80 (20 castelados + matriz LGA) | **36** (30 GPIO) |
| Antena | traço no módulo, com recorte na placa | **cerâmica integrada** |
| GPIO que o projeto usa | 19 | 20 (um a mais, ver abaixo) |

A largura é o ganho maior: o [04](04-placa.md#o-contorno) registra que *"a
largura de 16 mm é o limite do pod… o módulo tem 12 mm de largura e é ele
que põe o piso"*. Com 10 mm o piso desce e a placa vai a 14, o que leva o
pod de 19,4 para 17,4 mm de largura — **abaixo da faixa inteira da classe de
referência** (18 a 22 mm). E os cerca de 4 mm de comprimento que a peça mais
curta devolve são quase exatamente o que a vedação da case custa
([07](07-pod.md#o-envelope)).
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

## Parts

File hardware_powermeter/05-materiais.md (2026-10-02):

# Materiais por folha

O que cada folha do esquemático consome, com o designador de referência,
o footprint que a placa usa e o código de distribuidor quando ele já foi
anotado. Esta página **não substitui** a [lista de componentes](01-lista-de-componentes.md),
que traz o número do datasheet de cada peça e as razões da escolha; ela
diz **quantas peças cada folha pede** e o que cada uma faz no circuito.
A fonte é [`cad/parts.py`](cad/parts.py) e [`cad/footprints.py`](cad/footprints.py).

**Nesta página:** [Como ler](#como-ler) · [Folha 1 · Energia](#folha-1--energia) · [Folha 2 · MCU e depuração](#folha-2--mcu-e-depuração) · [Folha 3 · Ponte e conversor](#folha-3--ponte-e-conversor) · [Folha 4 · Sensores](#folha-4--sensores) · [Contagem](#contagem) · [O que ainda não tem código](#o-que-ainda-não-tem-código-de-compra)

> [!WARNING]
> **Nada foi comprado, nada foi montado.** Os códigos LCSC anotados vêm
> da [lista de componentes](01-lista-de-componentes.md) e estão marcados
> "a conferir" onde não foram batidos contra a página do distribuidor no
> dia do pedido.

## Como ler

- **Referência**: o designador do esquemático. O **primeiro dígito é a
  folha**: `1xx` energia, `2xx` MCU e depuração, `3xx` ponte e conversor,
  `4xx` sensores. `U` integrado, `R` resistor, `C` capacitor, `L` indutor,
  `FB` ferrite, `D` diodo e LED, `J` conector, `TP` ponto de teste.
- **Footprint**: o nome no `pmeter.kicad_pcb`. Os da biblioteca do KiCad 8
  aparecem com o prefixo da biblioteca; os desenhados aqui, com o prefixo
  `pmeter:` e a cota da ficha em `footprints.PACOTE`.
- **Quantidade**: por placa.
- Os passivos são **0402** salvo onde a ficha pede mais capacitância do
  que um 0402 aguenta (2,2 µF/25 V, 10 µF, 22 µF e 4,7 µF em **0603**).

## Folha 1 · Energia

| Referência | Componente | Valor ou código | Footprint | Qtd | Código |
|---|---|---|---|---|---|
| J101 | Conector magnético de 6 contatos, 2 fileiras de 3 | **genérico**, passo 2,5 mm, 1 A por contato, ouro | `pmeter:Pogo_Magnetico_6P_2x3_P2.5mm` (corpo 8,6 × 4,6 × 3,2 no courtyard de 9,0 × 5,0; footprint e corpo 3D **deste projeto**, a trocar pelo desenho do fornecedor) | 1 | **sem fornecedor** ([06](06-conectores-e-pontos-de-teste.md#j101--conector-magnético)) |
| D101 | ESD dos quatro sinais do conector | TI TPD4E05U06DQAR, USON-10 | `pmeter:TPD4E05U06_USON-10_1x2.5mm_P0.5mm` | 1 | C138714 |
| U101 | Carregador Li-ion e buck de 3,0 V | Nordic nPM1100-QDAB, QFN-24 4 × 4 | `Package_DFN_QFN:QFN-24-1EP_4x4mm_P0.5mm_EP2.7x2.7mm` | 1 | C2903119, a conferir |
| U102 | Medidor de carga ModelGauge, 0x36 | Analog Devices MAX17048G+T10, TDFN-8 | `Package_DFN_QFN:TDFN-8-1EP_2x2mm_P0.5mm_EP0.8x1.2mm` | 1 | C2680383, a conferir |
| J102 | Conector da célula | **JST `SM02B-SRSS-TB`** — série SH, 1,0 mm, 2 vias, **entrada lateral**, 2,90 mm. A célula entra pelo plugue `SHR-02V-S` do próprio pack, que é **requisito de compra** dela | `Connector_JST:JST_SH_SM02B-SRSS-TB_1x02-1MP_P1.00mm_Horizontal` | — | a série é o que fixa o teto da tampa do pod ([06](06-conectores-e-pontos-de-teste.md#j102--célula)) |
| L101 | Indutor do buck | 2,2 µH, ≤ 400 mΩ, Isat ≥ 350 mA (Murata DFE201610E-2R2M) | `Inductor_SMD:L_0805_2012Metric` | 1 | C296426 |
| C101 | `VBUS` do nPM1100 | 2,2 µF, 25 V | 0603 | 1 | — |
| C102 | `VOUTB`, o trilho `3V0` | 22 µF | 0603 | 1 | — |
| C103 | `DEC` | 1 µF | 0402 | 1 | — |
| C104 | `VBAT` junto do nPM1100 | 10 µF | 0603 | 1 | — |
| C105 | `VDD` do MAX17048 | 100 nF | 0402 | 1 | — |
| C106 | `VSYS` | 100 nF | 0402 | 1 | — |
| R101 | `ICHG`: 625 / 0,0747 − 1562,5 | 6,8 kΩ | 0402 | 1 | — |
| R102 | `NTC` ao `AVSS`, pack sem termistor | 10 kΩ | 0402 | 1 | — |
| R103, R104 | Pull-ups de `CHG_N` e `ERR_N` | 100 kΩ | 0402 | 2 | — |
| R105 | Pull-up de `GAUGE_ALRT` | 100 kΩ | 0402 | 1 | — |
| R106 | `SHPHLD` ao `VBAT` | 1 MΩ | 0402 | 1 | — |
| R107, R108 | Série do SWD entre o conector e o módulo | 100 Ω | 0402 | 2 | — |
| TP101 a TP104 | `VBUS`, `VBAT`, `3V0`, `GND` | pad de 1,0 mm, **na face de trás** | `TestPoint:TestPoint_Pad_D1.0mm` | 4 | — |

## Folha 2 · MCU e depuração

| Referência | Componente | Valor ou código | Footprint | Qtd | Código |
|---|---|---|---|---|---|
| U201 | Módulo de rádio com o nRF54L15 | HOLYIOT-26001-A, 10,0 × 12,5 × 2,4 (a altura é reserva: não consta do desenho), antena cerâmica | `pmeter:HOLYIOT_26001A_10x12.5mm` (36 pads meio-furo, gerado das cotas do desenho mecânico) | 1 | a comprar do fabricante (AliExpress) |
| FB201 | Ferrite do filtro pi do módulo | 600 Ω a 100 MHz (Murata BLM15PX601SN1D) | `Inductor_SMD:L_0603_1608Metric` | 1 | C76909 |
| C201 | `VDD` do módulo, a 0,5 mm do pad 19 | 100 nF | 0402 | 1 | — |
| C202, C203 | Reserva dos dois lados do ferrite | 4,7 µF | 0603 | 2 | — |
| J201 | Gravação de fábrica e bancada | Tag-Connect TC2030-IDC-NL (só pads e furos de alinhamento) | `Connector:Tag-Connect_TC2030-IDC-NL_2x03_P1.27mm_Vertical` | 1 | cabo, não peça |
| D201 | LED RGB de anodo comum | TUOZHAN S4-3528RGBTA-A, 3,5 × 2,8 × 1,9 | `pmeter:LED_RGB_3528_3.5x2.8mm` | 1 | C2827321 |
| R201, R202, R203 | Série dos três catodos | 1,5 kΩ | 0402 | 3 | — |
| R204, R205 | Pull-ups do I2C, junto do mestre | 4,7 kΩ | 0402 | 2 | — |
| TP201, TP202 | Console `UART_TX` e `UART_RX` | pad de 1,0 mm, na face de trás | `TestPoint:TestPoint_Pad_D1.0mm` | 2 | — |

## Folha 3 · Ponte e conversor

| Referência | Componente | Valor ou código | Footprint | Qtd | Código |
|---|---|---|---|---|---|
| J301 | Furos dos fios da ponte e da blindagem | cinco furos metalizados de 0,9 mm em ilhas de 1,5, passo 2,0 | `pmeter:Furos_Ponte_5x1.5mm_P2mm` | 1 | — (é cobre) |
| U301 | Conversor de 24 bits da ponte | TI ADS1220IRVAR, VQFN-16 3,5 × 3,5 | `Package_DFN_QFN:Texas_RVA_VQFN-16-1EP_3.5x3.5mm_P0.5mm_EP2.14x2.14mm` | 1 | C123398, a conferir |
| U302 | Chave da excitação | TI TPS22916BYFPR, DSBGA-4 | `pmeter:TPS22916_DSBGA-4_0.78x0.78mm_P0.4mm` | 1 | C2917017, a conferir |
| R301, R302 | Série das entradas (filtro da figura 9-11) | 1 kΩ | 0402 | 2 | — |
| C301 | Capacitor diferencial das entradas | 47 nF, C0G | 0402 | 1 | — |
| C302, C303 | Modo comum de cada entrada | 4,7 nF, C0G | 0402 | 2 | — |
| C304 | Referência `REFP0`–`REFN0` | 100 nF | 0402 | 1 | — |
| C305, C306 | `AVDD` e `DVDD` do ADS1220 | 100 nF | 0402 | 2 | — |
| C307 | `VOUT` da chave | 100 nF | 0402 | 1 | — |
| C308 | `VIN` da chave | 1 µF | 0402 | 1 | — |
| TP301 | `3V0_EXC` | pad de 1,0 mm, na face de trás | `TestPoint:TestPoint_Pad_D1.0mm` | 1 | — |

## Folha 4 · Sensores

| Referência | Componente | Valor ou código | Footprint | Qtd | Código |
|---|---|---|---|---|---|
| U401 | Acelerômetro de 3 eixos | Bosch BMA400, LGA-12 2 × 2 | `Package_LGA:LGA-12_2x2mm_P0.5mm` | 1 | C542206, a conferir |
| U402 | Temperatura da ponte, ±0,1 °C | TI TMP117AIDRVR, WSON-6 2 × 2 | `Package_SON:WSON-6-1EP_2x2mm_P0.65mm_EP1x1.6mm` | 1 | C2687591, a conferir |
| C401, C402 | `VDD` e `VDDIO` do BMA400 | 100 nF | 0402 | 2 | — |
| C403 | `V+` do TMP117 | 100 nF | 0402 | 1 | — |

## Contagem

| Folha | Posições | Integrados | Passivos | Conectores e pontos de teste |
|---|---|---|---|---|
| 1 · Energia | 24 | 3 (U101, U102, D101) | 15 (6 C, 8 R, 1 L) | J101, J102, TP101 a TP104 |
| 2 · MCU e depuração | 14 | 2 (U201, D201) | 9 (3 C, 5 R, 1 FB) | J201, TP201, TP202 |
| 3 · Ponte e conversor | 14 | 2 (U301, U302) | 10 (8 C, 2 R) | J301, TP301 |
| 4 · Sensores | 5 | 2 (U401, U402) | 3 C | — |
| **Total** | **57** | **9** | **37** | **11** |

Os totais saem de `python cad/sheets.py`.

## O que ainda não tem código de compra

| Peça | Situação |
|---|---|
| J101, o conector magnético | nenhuma página de fornecedor pôde ser alcançada em 2026-09-27; o footprint é um lugar reservado e a numeração dos contatos é deste projeto ([06](06-conectores-e-pontos-de-teste.md#j101--conector-magnético)) |
| U201, o módulo | compra direta do fabricante, como no ciclocomputador |
| os passivos | genéricos; os C0G do filtro da ponte (C301 a C303) são a única exigência de dielétrico |
| a célula | envelope de 25 × 15 × 4 mm reservado no pod ([07](07-pod.md)); a célula não foi escolhida |

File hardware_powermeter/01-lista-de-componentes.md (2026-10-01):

# Lista de componentes (fase 1: módulo no braço do pedivela)

Lista fechada em 2026-09-27. Cada peça tem o datasheet baixado do fabricante e conferido (os PDF ficam em [`datasheets/`](datasheets/), fora do git). Os números abaixo são os do datasheet, com o documento indicado. O estudo que levou a esta lista está no doc "Medidores de potência para bicicleta: estudo para o projeto" (Claude Docs, 2026-09-27).

**Nesta página:** [Decisão](#decisão) · [A placa](#a-placa) · [Extensômetros](#extensômetros) · [Fora da placa](#fora-da-placa) · [O que ficou de fora](#o-que-ficou-de-fora) · [Não verificado](#não-verificado)

## Decisão

O sensor é o **TI ADS1220**: 0,26 µV RMS de ruído com ganho 128 a 175 amostras/s, 585 µA medindo, 0,4 µA desligado, referência ratiométrica, 3,5 × 3,5 mm. O conversor não é o limite dos ±1 a 2 %; a colagem, a temperatura e a calibração são. A compensação de temperatura fica no firmware, aberta e testada no PC.

```mermaid
flowchart LR
    G["Ponte completa<br/>1 kΩ, classe transdutor"] --> A["ADS1220<br/>ganho 128, ratiométrico"]
    SW["TPS22916<br/>excitação chaveada"] --> G
    SW --> A
    A --> M["HOLYIOT-26001-A<br/>nRF54L15"]
    I["BMA400<br/>cadência e ângulo"] --> M
    T["TMP117<br/>temperatura da ponte"] --> M
    M --> R["BLE Cycling Power<br/>ANT+ Bicycle Power"]
    P["nPM1100<br/>carga + buck 3,0 V"] --> M
    P --> SW
    F["MAX17048<br/>estado da bateria"] --> M
    C["Conector magnético<br/>5 V, USB, SWD"] --> P
    C --> M
```

## A placa

| Bloco | Peça | Datasheet | Números conferidos | Driver no NCS v3.3.0 |
|---|---|---|---|---|
| Conversor da ponte | **TI ADS1220**, VQFN-16 | SBAS501D (rev. maio 2026) | Ganho 128, modo normal, AVDD 3,3 V: 0,09 µV RMS a 20 SPS, 0,18 a 90, 0,26 a 175. Corrente AVDD com ganho 64 ou 128: 135 µA em duty-cycle, 510 normal, 890 turbo; DVDD 55, 75, 95 µA; power-down 0,1 µA (3 máx.), 400 nA típico. Referência externa de 0,75 V até AVDD. Referência interna 2,048 V, 5 ppm/°C. Sensor de temperatura 0,5 °C. 2,3 a 5,5 V. 3,5 × 3,5 mm. −40 a +125 °C | Não: driver próprio em `zephyr_app/modules/pm_drivers` |
| Alternativa com driver pronto | TI ADS124S06, VQFN-32 | SBAS660C (rev. junho 2017) | 19 nV RMS com ganho 128; 250 µA AVDD + 225 µA DVDD medindo com referência externa; +185 µA se usar a referência interna de 2,5 V; power-down 0,1 µA; 5 × 5 mm; SPI com CRC, calibração de sistema, detecção de falhas | Sim: `ti,ads124s06` |
| Alternativa com compensação no chip | Renesas ZSSC3224, PQFN-24 | Datasheet Renesas | Ganho 6,6 a 216, ADC de 12 a 24 bits, compensação de 1ª e 2ª ordem em memória MTP, erro do CI 0,01 % FSO, 1050 µA ativo, 20 nA sleep, 24 bits a 60 Hz, 1,68 a 3,6 V, 4 × 4 mm | Não |
| Acelerômetro | **Bosch BMA400**, LGA-12 | BST-BMA400-DS000-14 (rev. 2.3, julho 2025) | 14,5 µA normal (OSR 3) ou 3,5 µA (OSR 0), 850 nA em low-power a 25 Hz, 160 nA em sleep; ODR 12,5 a 800 Hz; ±2 a ±16 g; FIFO de 1 kB; VDDIO 1,2 a 3,6 V; 2 × 2 × 0,95 mm | **Não: driver próprio.** O `bosch,bma4xx` da árvore reconhece o chip ID `0x90` com um aviso e **não opera a peça**: ele usa o mapa de registradores do BMA422 (dados em `0x12`, configuração em `0x40`) e o BMA400 tem outro (`0x04`, `0x19`). O driver está em `zephyr_app/modules/pm_drivers/drivers/sensor` ([`docs/04`](../docs/04-arquitetura-firmware.md)) |
| Temperatura da ponte | **TI TMP117**, WSON-6 | Datasheet TI | ±0,1 °C máx. de −20 a 50 °C, 16 bits (0,0078 °C), 3,5 µA a 1 Hz, 150 nA desligado, 1,7 a 5,5 V, 2 × 2 mm, I2C | Sim: `ti,tmp11x` |
| Carga e trilho de 3,0 V | **Nordic nPM1100**, QFN-24 4 × 4 mm | Product Specification v1.5 | Carregador Li-ion de 20 a 400 mA por resistor, JEITA, terminação selecionável; VBUS de 4,1 a 6,7 V (20 V absoluto); buck de 1,8 a 3,0 V e 150 mA; 800 nA quiescente, 460 nA em ship mode; sem interface de controle; LED de carga e erro | Não precisa (pinos) |
| Alternativa | TI BQ25180 (DSBGA-8) + TI TPS62840 (SON-8) | Datasheets TI | BQ25180: 5 mA a 1 A, proteções OVP, UVLO, curto, sobrecorrente, térmica, ship mode 3,2 µA, 15 nA desligado, I2C. TPS62840: buck de 60 nA quiescente, 750 mA, 1,8 a 6,5 V, 16 tensões por pino | BQ25180: `ti,bq25180` |
| Medidor de bateria | **MAX17048**, TDFN-8 2 × 2 mm | 19-6171 (rev. 7, novembro 2016) | ModelGauge sem resistor de sentido, ±7,5 mV, 3 µA em hibernate, I2C, alerta | Sim: `maxim,max17048` |
| Chave da excitação | **TI TPS22916** | Datasheet TI | 1 a 5,5 V, 2 A, 60 a 200 mΩ, 0,5 µA ligado, 10 nA desligado, bloqueio de corrente reversa | GPIO |
| Proteção dos sinais do conector | **TI TPD4E05U06** | Datasheet TI | IEC 61000-4-2 ±12 kV contato e ±15 kV ar, 0,42 a 0,5 pF por canal, 6,5 V de ruptura, 10 nA de fuga; quatro canais: D+, D−, SWDIO, SWCLK | Passivo |
| Diodo ideal no VBUS (opcional) | TI LM66100 | Datasheet TI | 1,5 a 5,5 V, 1,5 A, 79 a 141 mΩ, 150 nA quiescente | Passivo |
| LDO de 3,0 V (só se o buck sair) | TI TPS7A02 | SBVS277C | 25 nA quiescente, 3 nA desligado, 200 mA, 1,5 %, 1,5 a 6 V, X2SON 1 × 1 mm ou SOT23-5 | Regulador |
| MCU e rádio | **HOLYIOT-26001-A** (nRF54L15, antena cerâmica) | não há ficha em PDF: o desenho mecânico do anúncio do fabricante | 10,0 × 12,5 mm, 36 pads, 30 GPIO; BLE, ANT+ (add-on `sdk-ant`); **sem USB** (o SoC não tem `usbhs`), a porta serial passa para a UART do conector magnético ([09](09-modulo-de-radio.md)). A altura do corpo não consta em lugar nenhum: o projeto reserva 2,4 mm, o mesmo do módulo que saiu | Sim, mais o add-on ANT |
| Versão I2C do conversor | TI ADS122C04, WQFN-16 | SBAS751B | Os mesmos 20 bits efetivos, 315 µA, I2C, 3 × 3 mm | Não |
| Bateria | LiPo de bolsa classe **`501415`**: 5,0 × 14 × 15 mm, **≥ 81 mAh**, dois fios já soldados e proteção (PCM) integrada | **nenhuma listagem foi alcançada**, e em 2026-10-01 o levantamento ficou conclusivo: seis lojas brasileiras foram lidas com o catálogo aberto (Curto Circuito, Usinainfo, Baú da Eletrônica, Huinfinito, Eletrogate e Vida de Silício) e **nenhuma estoca bolsa LiPo pequena** — só pilha-botão, 18650 e 9 V. Quem as vende no Brasil são os anunciantes de marketplace e os importadores ([12](12-comparacao-com-a-classe.md#a-célula-o-levantamento-nas-lojas-e-o-que-comprar)). O envelope e a capacidade são **requisito de compra**, não uma peça escolhida | A 0,68 mA (ponte de 5 kΩ com o conversor em duty-cycle), 81 mAh valem **119 h** contra as 50 h do requisito. O nome `501415` é o código de tamanho usual do ramo: 5,0 mm de espessura, 14 mm de largura, 15 de comprimento. O envelope mudou em 2026-09-30, quando a célula saiu de baixo da placa e foi para a baía AO LADO dela | |
| Conector | Magnético de 6 contatos em 2 × 3, ímã com polaridade | **não existe**: nenhum fornecedor foi alcançado, o desenho é deste projeto | 5 V, GND, D+, D−, SWDIO, SWCLK; as molas ficam no **cabo** e os alvos chatos no aparelho, que é o que a vedação exige; cabo com USB-serial e saída SWD de 10 vias ([06](06-conectores-e-pontos-de-teste.md#j101--conector-magnético)) | |
| Indicação | LED RGB de baixa corrente | | Pareamento, calibração, carga (o nPM1100 tem saídas de LED) | |

Topologia dos trilhos: o buck do nPM1100 dá 3,0 V para o módulo, o ADS1220 e os sensores; a excitação da ponte sai desse trilho pela TPS22916 e vai também aos pinos REFP0 e REFN0 do ADS1220, então o ruído do buck cancela na medição ratiométrica. A ponte de 1 kΩ a 3,0 V drena 3 mA só enquanto a chave está ligada.

## Extensômetros

Não são circuitos integrados, mas definem a precisão. Referência: Micro-Measurements (Vishay Precision Group), páginas abertas em 2026-09-27.

| O que | Escolha | Fonte |
|---|---|---|
| Padrão | **Ponte completa numa peça só, de flexão**, classe transdutor: um filme, uma colagem, um alinhamento, com as quatro grades já posicionadas e ligadas de fábrica. Era alternativa nesta linha e vira a escolha, por dois motivos medidos: o padrão de cisalhamento a 45° é de torquímetro de eixo e dá 8,9 vezes menos sinal num braço de pedivela ([`docs/06`](../docs/06-medicao-e-calibracao.md#cisalhamento-ou-flexão-o-padrão-especificado-está-errado)), e quatro colagens separadas multiplicam por quatro o erro de alinhamento, que é o gargalo da precisão | [Transducer Class](https://www.micro-measurements.com/transducer-class); `docs/06` |
| Padrões de análise (para a bancada) | CEA 062UV e 187UVA (350 Ω), CEA 125US e 250USA (120, 350 e 1000 Ω), C2A 062LV | [Shear and torque patterns](https://www.micro-measurements.com/shear-pattern-strain-gages) |
| Resistência | **5 kΩ** (decisão do dono). O guia do fabricante nomeia 120, 350, 1 k e 5 kΩ e diz que, havendo escolha, a resistência mais alta é preferível: gera menos calor na grade, sofre menos dessensibilização pelo fio e melhora a relação sinal-ruído, por permitir excitação maior sem auto-aquecimento | Guia de seleção, p. 4, citado |
| Fios já presos | **Opção P2**, que pelo fabricante "praticamente elimina a necessidade de soldar durante a instalação": cabo de 3,1 m, 30 AWG estanhado, grade inteira encapsulada, vida em fadiga inalterada e sem aumento de rigidez. **Dois poréns medidos:** o cabo da P2 tem **três** condutores e uma ponte cheia precisa de quatro, então para o padrão de ponte cheia a fiação tem de ser confirmada peça a peça; e o limite é −50 a +80 °C, pelo vinil, que cobre com folga os −10 a +50 °C do requisito. A alternativa é a **opção W**, terminais de circuito impresso já presos, que aceita fio mais grosso mas encurta a vida em fadiga e engrossa a peça | Guia de seleção, p. 5 e 6, citado |
| Compensação térmica | S-T-C casado com o material: 13 para alumínio (braço), 06 para aço (eixo) | Guia de seleção |
| Cola | M-Bond AE-10 ou AE-15 para o módulo (resistentes à umidade); M-Bond 200 para a bancada | Guia de seleção, p. 8 |
| Proteção | 3145 RTV + M-Coat B para longo prazo | Guia de seleção, p. 9 |

### A peça, achada no databook do fabricante (2026-09-28)

O databook de classe transdutor (2622-EN, rev. 12-ago-2019, 116 páginas, em `datasheets/`) responde a pergunta: **existe ponte completa numa peça só em 5 kΩ.** O próprio documento diz, na página 7, que os padrões de alta resistência são oferecidos "em configurações linear, de cisalhamento, tee e **de ponte completa**, com até 10 kΩ". Estes são os candidatos, todos com as quatro grades num filme e a ponte já balanceada de fábrica:

| Padrão | Designação | Ω | Matriz | Descrição do databook |
|---|---|---|---|---|
| **S5229** | `N2K-13-S5229A-50C/DG/E3` | 5000 ±5 % | **4,0 × 3,7 mm** | ponte completa miniatura de alta resistência, balanceada a ±0,5 mV/V |
| S5020 | `N2K-13-S5020Q-50C/DG/E3` | 5000 ±5 % | 4,3 × 4,7 mm | idem, balanceada a ±0,4 mV/V |
| S5046 | `N2K-13-S5046M-50C/DG/E5` | 5000 | 4,5 × 4,8 mm | ponte completa aberta, para cisalhamento ou torque |
| S5067 | `N2K-13-S5067P-10C/DG/E5` | 1000 ±3 % | 4,3 × 4,3 mm | ponte completa pequena **para vigas em flexão** |
| S5062 | `N2K-13-S5062N-10C/DG/E5` | 1000 ±3 % | 4,2 × 4,8 mm | idem |

**Recomendação: S5229.** É a menor das cinco, cabe folgado no braço, é de 5 kΩ, o que mantém o consumo em 1,5 mA — 0,68 mA com o conversor em duty-cycle — e o pod em 10,0 mm, e vem com a ponte balanceada a ±0,5 mV/V, o que reduz o zero a calibrar. O desenho do padrão mostra quatro grades, **duas longitudinais e duas transversais**: é ponte de Poisson, que num campo de flexão entrega cerca de dois terços da saída de uma ponte de flexão pura, e ainda assim cerca de seis vezes o que o cisalhamento daria.

**Como se lê a designação:** `N2K` é a série, padrões de liga Karma modificada sobre filme de poliimida, com ilhas de solda douradas (`DG`) e encapsulamento epóxi; `13` é o número de autocompensação térmica, que o databook diz ser o de estoque para **ligas de alumínio** (`06` é o de aços), e é ele que casa o extensômetro com o material do braço.

### Os braços do dono, e o que eles fecham (2026-09-28)

O dono começa pelos **Shimano 105 e Ultegra**, os dois de **liga de alumínio**, e quer depois cobrir SRAM e braços de aço e de carbono. O alumínio fecha o código: **S-T-C 13**. A designação de compra fica

> **`N2K-13-S5229A-50C/DG/E3`**

**Duas armadilhas de compra, do próprio databook:** se o código não for escrito no pedido, o fabricante **embarca o 06**, que é o de aço, e num braço de alumínio isso faz a leitura andar com a temperatura. E o fator de grade da liga K, que é a do N2K, é **2,1**, não 2,0: as contas deste projeto usaram 2,0 e ficam conservadoras em 5 %.

**Braço Shimano é oco, e isso melhora o sinal.** Refazendo a conta com parede de 3 mm numa seção externa de 20 × 14 mm, o momento de inércia cai de 9.333 para 7.504 mm⁴ e a deformação sobe de 459 para **571 µε**, 24 % mais. Com a ponte de Poisson do S5229, que entrega cerca de dois terços de uma ponte de flexão pura, a saída fica em **2,28 mV** a 3,0 V, dentro da faixa que [`docs/06`](../docs/06-medicao-e-calibracao.md) sempre assumiu.

**Para os outros materiais da fase seguinte:**

| Material | O que muda |
|---|---|
| Aço (SRAM e outros) | só o código: `N2K-06-S5229A-50C/DG/E3`. Mesma peça, mesma colagem |
| Carbono | não é só o código. O databook diz que resistências altas são usadas justamente em compósitos, mas o S-T-C é o coeficiente de dilatação do material em ppm/°F, e o de carbono-epóxi é perto de zero na direção das fibras: o número sai do sistema de designação por liga, e ainda há a camada rica em resina da superfície e a anisotropia. É estudo à parte, não troca de código |

Cada braço muda a inclinação, porque muda a seção e a distância da colagem ao pedal. Isso **não é problema**: a inclinação é calibrada por unidade, com massa pendurada, e é justamente o que permite cobrir vários pedivelas com a mesma eletrônica. O que muda de verdade por modelo é a **largura da face interna** e o raio de concordância, que decidem se o pod assenta.

**O que ainda falta:** preço e prazo com o distribuidor. Se o S5229 não vier em `13`, a saída é o S5067 em 1000 Ω com o modo duty-cycle do conversor, que dá 1,40 mA e mantém o pod ([`docs/02`](../docs/02-hardware.md#orçamento-de-consumo)).

**Onde estão os catálogos:** biblioteca do fabricante, PDF direto, sem cadastro. Classe transdutor `docs.micro-measurements.com/?id=12970`; extensômetros de precisão `?id=4079`; acessórios `?id=12967`; instrumentação `?id=4078`.

## Fora da placa

- Um braço esquerdo usado, igual ao do ciclista, para a bancada.
- ADS1232 em placa de avaliação como referência de bancada (SBAS350H: 17 nV RMS a 10 SPS com ganho 128, mas 1,35 mA e só 80 SPS).
- Massas de 5 a 20 kg e um medidor comercial de referência para a prova de estrada.

## O que ficou de fora

| Peça | Motivo |
|---|---|
| Avia HX711 | Ruído, consumo e alimentação de 5 V; peça de balança de cozinha |
| TI ADS1235 | 23 mW e alimentação de 5 V ou ±2,5 V |
| TI PGA302 | Saída analógica e alimentação de 4,5 a 20 V |
| Renesas ZSSC3218 | Só existe como die |
| MAX17262 | WLP de 1,5 mm; o MAX17048 tem TDFN e driver pronto |

## Não verificado

A Analog Devices e a ST recusaram a conexão desta máquina em todos os caminhos (site, DigiKey, Arrow, alldatasheet, GitHub): **AD4130-8**, **AD7124-4** e **LIS2DW12** não entraram na lista. O AD4130-8 é o único que poderia bater o ADS1220 em consumo (excitação e chave da ponte com duty-cycle interno, driver `adi,ad4130-adc` no Zephyr). Se o datasheet chegar, a comparação é refeita com os mesmos critérios.

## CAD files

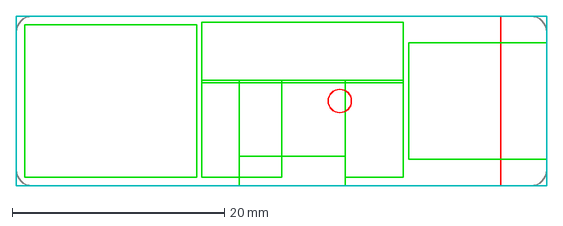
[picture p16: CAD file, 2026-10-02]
hardware_powermeter/cad/zonas.dxf
50.0 x 16.0 mm

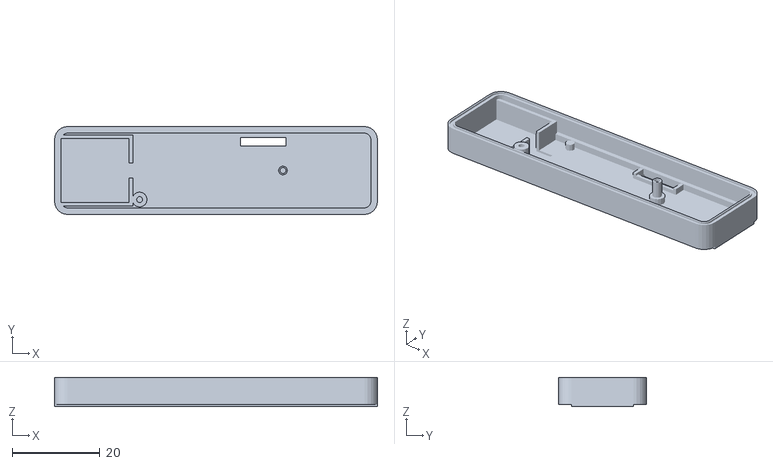
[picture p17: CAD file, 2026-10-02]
hardware_powermeter/pod/pod-concha.stl
73.4 x 20.0 x 6.70

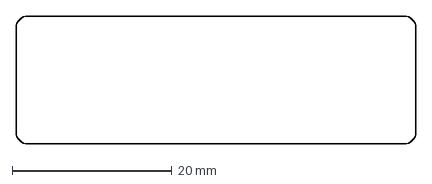
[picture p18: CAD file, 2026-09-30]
hardware_powermeter/cad/contorno.dxf
50.0 x 16.0 mm

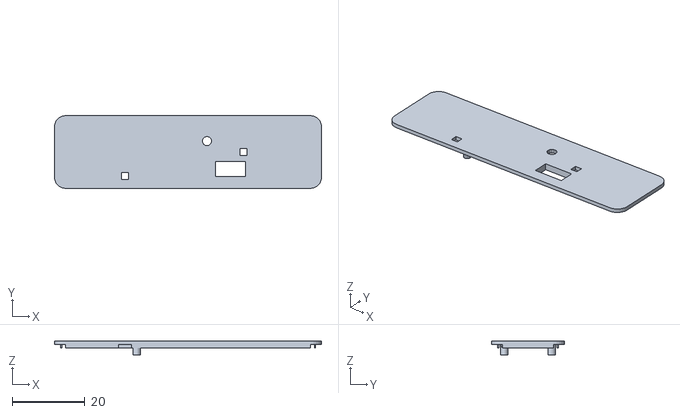
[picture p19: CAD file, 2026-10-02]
hardware_powermeter/pod/pod-tampa.stl
73.4 x 20.0 x 3.90

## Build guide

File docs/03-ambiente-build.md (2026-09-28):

# Ambiente e build

O mesmo do ciclocomputador: NCS v3.3.0 em `C:\ncs`, scripts em `tools/fw/` (`fw.sh build`, `flash`, `recover`, `devices`, `size`), `ANT=1` para o add-on `sdk-ant`, testes de host por `tools/fw/host_tests.sh` (GCC do MinGW-w64 em `C:\ProgramData\mingw64`, Unity 2.6.1 por `FetchContent`, um executável por módulo do modelo em `zephyr_app/tests/host/build/host-tests/`). `bash tools/fw/host_tests.sh coverage` recompila em `build/host-cov` com `--coverage`, roda tudo e chama `tools/fw/coverage.py`, que junta os `.gcov` de todos os executáveis e falha se algum módulo de `zephyr_app/src/model/` ficar abaixo de 95 % das linhas. Nunca WSL.

## Build do firmware

| Tarefa | Comando (Git Bash, na raiz) |
|---|---|
| Build incremental / do zero para o nRF54LM20 DK (o alvo de desenvolvimento) | `bash tools/fw/fw.sh build` / `bash tools/fw/fw.sh build pristine` |
| Build com ANT+ (add-on `sdk-ant` em `C:\ncs\sdk-ant`, módulo `zephyr_app/modules/ant_ncs33_compat`) | `ANT=1 BUILD_DIR=zephyr_app/build_ant bash tools/fw/fw.sh build pristine` |
| Build para a placa própria do pod (`zephyr_app/boards/pm/pmboard`) | `BOARD=pmboard/nrf54l15/cpuapp BUILD_DIR=zephyr_app/build_custom bash tools/fw/fw.sh build` |
| Conferir o mapa de pinos contra o silício, contra a tabela de [02](02-hardware.md#pinos-do-módulo) e contra a lista de nós do esquemático | `python tools/fw/board_check.py` |
| Gravar no DK (apaga tudo / mantém settings) | `bash tools/fw/fw.sh flash` / `bash tools/fw/fw.sh flash keep` |
| Pilhas (`CONFIG_STACK_USAGE`, skill `fw-threads`) | `west build -d build_su ... -Dzephyr_app_CONFIG_STACK_USAGE=y` de dentro de `zephyr_app`, e somar os `.su` da cadeia mais funda |

**Referência de 2026-09-28**, medida em build do zero nos três alvos, com sysbuild e MCUboot, e com a mesma tabela de partições nos três devicetrees (slot de 659.312 B, bootloader de 60 KB):

| Alvo | FLASH da aplicação | RAM | MCUboot |
|---|---|---|---|
| `pmboard/nrf54l15/cpuapp` (o pod) | 256.872 B (38,96 %) | 108.548 B de **188 KB** (56,39 %) | 46.996 B de 60 KB (76,49 %) |
| `nrf54lm20dk/nrf54lm20a/cpuapp` | 290.312 B (44,03 %) | 119.404 B de 511 KB (22,82 %) | 53.324 B de 60 KB (86,79 %) |
| o mesmo, `ANT=1` | 325.592 B (49,38 %) | 124.068 B (23,71 %) | idem |

A RAM do pod é o número a vigiar: 188 KB contra os 511 do nRF54LM20A. **Zero avisos de compilador** nos três builds. Os que aparecem não são de código do projeto: com `ANT=1`, o símbolo depreciado `SOC_SERIES_NRF54LX` que o módulo de compatibilidade religa, e um `unused variable` dentro do próprio `ant_bpwr.c` do add-on; e na imagem do MCUboot do pod, `lto-wrapper.exe: warning: using serial compilation of 2 LTRANS jobs`, que é o compilador dizendo que não paralelizou a otimização de ligação. O CMake dá dois avisos esperados: `No SOURCES given to Zephyr library` para `drivers__adc` e `drivers__sensor`, porque os drivers dessas classes moram em `zephyr_app/modules/pm_drivers`, e a chave de desenvolvimento do MCUboot. Nada disso rodou em placa nem no DK: não há DK com as placas de avaliação ligadas ainda.

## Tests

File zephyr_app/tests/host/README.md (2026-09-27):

# Testes de host

Mesmo esquema do ciclocomputador: `bash tools/fw/host_tests.sh` compila os módulos de `src/model` com o GCC do PC (MinGW-w64) e roda o Unity pelo CTest; `bash tools/fw/host_tests.sh coverage` compila com `--coverage` e chama `tools/fw/coverage.py`, que falha se qualquer módulo do modelo ficar abaixo de 95 % de linhas. Os módulos são C puro, sem shim de kernel: `shim/zephyr/` e `support/` ficam para o dia em que um precisar.

| Conjunto | Módulos | O que garante |
|---|---|---|
| `test_bridge_calc` | `bridge_calc` | código para torque com zero, inclinação e temperatura; saturação; validade |
| `test_crank_angle` | `crank_angle` | ω pelos cruzamentos do eixo tangencial, θ, volta no ponto baixo, repouso, saltos descartados |
| `test_rev_power` | `rev_power` | integração da volta, TE, PS, acumuladores e unidades do rádio |
| `test_calib` | `calib`, `bridge_calc` | zero com estabilidade, inclinação por mínimos quadrados com resíduo, ajuste de temperatura |
| `test_cps_encode` | `cps_encode` | os bytes do Cycling Power Service 1.1 |
| `test_pm_settings` | `pm_settings`, `bridge_calc` | limites, bloco versionado com CRC, chaves de texto |
| `test_health` | `health` | cada regra de saúde de `docs/06-medicao-e-calibracao.md` |
| `test_pm_fsm` | `pm_fsm` | cada transição da máquina do sistema e as recusadas |
| `test_pm_cmd` | `pm_cmd` | cada comando `$...`, cada `$NAK`, estouro de linha |

Um conjunto novo entra por `pm_add_test(...)` no `CMakeLists.txt`; o procedimento, o teste de mutação e o cppcheck estão na skill `fw-testes`.

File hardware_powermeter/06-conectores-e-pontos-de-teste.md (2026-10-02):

# Conectores e pontos de teste

Todo conector e todo ponto de teste da placa, **contato a contato**. As
[folhas do esquemático](02-esquematico.md) dizem quais sinais existem e a
[lista de nós](03-netlist.md) diz de onde cada um sai e aonde chega;
nenhuma das duas diz **em que contato** de cada conector o sinal entra. É
essa lacuna que este documento fecha, porque ela é a forma clássica de
inverter a polaridade da célula na primeira montagem.

**Nesta página:** [Como ler](#como-ler) · [De onde vem cada pinagem](#de-onde-vem-cada-pinagem) · [J101 · Conector magnético](#j101--conector-magnético) · [J102 · Célula](#j102--célula) · [J201 · Tag-Connect](#j201--tag-connect) · [J301 · Furos da ponte](#j301--furos-da-ponte) · [Pontos de teste](#pontos-de-teste) · [O que falta conferir](#o-que-falta-conferir)

> [!WARNING]
> **Nada disto foi montado, medido ou fabricado.** Cada pinagem abaixo
> vem de uma ficha de fabricante ou de uma escolha feita aqui, e está
> marcada como tal. O conector magnético **não tem fornecedor escolhido**:
> a sua numeração é deste projeto e muda com a peça.

## Como ler

- **Contato**: o número como o desenho do fabricante o numera; onde não há
  fabricante (o magnético), o número é o do footprint deste projeto.
- **Direção**: do ponto de vista **da placa**. `entrada` é o que chega,
  `saída` é o que a placa aciona, `bidir` é linha compartilhada, `alim` é
  alimentação ou retorno.
- **Origem da pinagem**: cada seção diz se a ordem dos contatos veio da
  **ficha do fabricante** ou é **escolha deste projeto**.
- Os designadores seguem o esquema por folha de [05](05-materiais.md#como-ler).

```mermaid
flowchart LR
    subgraph EXT["Fora do pod"]
        CABO["cabo magnético<br/>USB-A + SWD de 10 vias"]
        TC["cabo Tag-Connect<br/>TC2030 → J-Link"]
        PACK["célula com JST SH"]
        ARM["braço: ponte de extensômetros"]
    end
    subgraph PCB["Placa"]
        J101["J101 magnético<br/>6 contatos + 2 ímãs"]
        J102["J102 JST SH 2 vias"]
        J201["J201 Tag-Connect<br/>6 pads, 3 furos"]
        J301["J301<br/>5 furos"]
        TP["TP101 a TP104, TP201, TP202, TP301<br/>face de trás"]
    end
    CABO -.->|"pela janela da tampa"| J101
    TC -.->|"só com a placa nua"| J201
    PACK -->|"canal na ponta esquerda"| J102
    ARM -->|"rasgo no fundo do pod"| J301
```

## De onde vem cada pinagem

| Conector | Origem | Confiança |
|---|---|---|
| J101 magnético | **escolha deste projeto** sobre um footprint genérico | baixa: muda com a peça |
| J102 JST SH | ficha JST (mecânica); a polaridade é **escolha deste projeto** | média: a mandar ao fabricante do pack |
| J201 Tag-Connect | ficha do TC2030 (o padrão ARM de 6 vias) | alta |
| J301 furos | escolha deste projeto (ordem dos fios) | alta: são fios soldados, sem cabo padrão |

## J101 · Conector magnético

Seis contatos em **duas fileiras de três** a 2,5 mm, dois ímãs com
polaridade nos extremos, na face de cima da placa, atravessando a janela da
tampa do pod ([07](07-pod.md)). O cabo termina em USB-A (5 V, GND, D+, D−) e
numa saída SWD de 10 vias para o J-Link
([`docs/02`](../docs/02-hardware.md#conector-magnético)).

> [!IMPORTANT]
> **Nenhuma peça foi escolhida.** Todas as páginas de fornecedor tentadas em
> 2026-09-27 e 2026-09-28 estavam fora de alcance desta máquina. O footprint
> `pmeter:Pogo_Magnetico_6P_2x3_P2.5mm` e o corpo 3D são **deste projeto**,
> desenhados a partir do que o circuito e o pod exigem, e cada número abaixo
> é um **requisito de compra**, não uma medida. Quando a peça for escolhida,
> o footprint, a altura e a janela da tampa mudam com ela, e o dry run do pod
> mede os três.

### A peça que este projeto desenhou

| Medida | Valor | De onde vem |
|---|---|---|
| Contatos | 6, em 2 fileiras de 3, passo 2,5 mm | seis em fila custariam 12,5 mm só de contatos; em 2 × 3 ocupam 5,0 × 2,5 |
| Pad de cada contato | Ø 1,5 mm | escolha deste projeto |
| Abas dos ímãs | 0,8 × 4,4 mm em `x = ±3,9` | a 3,5 o cobre encostava no contato de 1,5 e o DRC acusava curto |
| Corpo | 8,6 × 4,6, dentro do courtyard de 9,0 × 5,0 | escolha deste projeto |
| Altura | **3,20 mm, no mínimo** | requisito do pod: a tampa fica a essa altura sobre a placa e a face do conector tem de alcançá-la |
| Chanfro do topo | 0,35 mm | para a cabeça do cabo se centrar sozinha em vez de parar numa quina viva |

**Os contatos chatos ficam no aparelho e as molas no cabo.** Um conector
magnético pode ser feito dos dois jeitos, e este é o que o pod exige: pôr as
molas na placa seria pôr seis peças móveis, seis barris e seis frestas numa
peça que tem de aguentar IPX7, poeira de estrada e jato de lavagem, e cada
barril é caminho de água para dentro de um corpo que é envasado e não abre
mais. Alvos chatos de ouro não têm o que emperrar nem por onde vazar; o
desgaste e o mecanismo vão para o cabo, que é barato de trocar e vive dentro
de casa. É o que faz qualquer aparelho vedado: num carregador de relógio as
molas estão no berço, não no relógio.

O corpo 3D em `cad/3d/Pogo_Magnetico_6P_2x3_P2.5mm.wrl` desenha exatamente
isso — caixa preta de LCP com chanfro, seis alvos de ouro de 1,3 mm 0,05 mm
salientes sobre os pads, dois ímãs niquelados de 1,1 × 4,2 × 2,6 expostos no
topo sobre as abas, e do lado da solda os seis pads estanhados e as duas
abas — e é o que aparece nas vistas 3D da placa.

| Contato | Sinal | Direção | Por quê nesta posição |
|---|---|---|---|
| 1 | `GND` | alim | na ponta, ao lado do 5 V |
| 2 | `VBUS` | entrada | ao lado do terra: um cabo forçado ao contrário põe 5 V no terra e terra no 5 V, um curto que a fonte do cabo aguenta, e não 5 V num sinal |
| 3 | `USB_DM` | bidir | par USB no meio, lado a lado |
| 4 | `USB_DP` | bidir | |
| 5 | `SWDIO_J` | bidir | par SWD na outra ponta, pelo TVS e por 100 Ω |
| 6 | `SWCLK_J` | entrada | |
| MP1, MP2 | `GND` | mecânico | as abas do quadro dos ímãs, soldadas ao terra |

Os quatro sinais passam pelo `D101` (TPD4E05U06, 12 kV de contato) antes
de chegar ao módulo; o `VBUS` entra no nPM1100, que é entrada, e nada sai
do pod pelos contatos sem cabo.

## J102 · Célula

**JST SM02B-SRSS-TB** na placa (série SH, passo 1,0 mm, 2 vias, **entrada
lateral**, 2,90 mm de altura, 1 A por contato) e **SHR-02V-S** no cabo do
pack. Fica em (3,5; 3,0) a **270°**, com a boca virada para a ponta
**esquerda** da placa: a baía da célula fica ao lado dela, naquela ponta, e o
plugue entra na horizontal pelo canal do pod ([07](07-pod.md)). O
`orientacao.py` mede a boca do footprint e confere o giro — foi ele que disse
que 270° é o ângulo.

> [!IMPORTANT]
> **A série importa, e é requisito de compra.** O SH tem 2,90 mm e é o que
> fixa o teto da tampa do pod em 3,20. Uma célula que chegue com **JST PH de
> 2,0 mm** — o conector comum nas células de hobby — tem receptáculo de 6 mm:
> **o pod não fecha com ele.** Ou a célula vem com SH, ou o plugue dela é
> trocado.

**Ele saiu e voltou.** Em 2026-09-26 o conector virou **dois furos
metalizados** para fio soldado, e o argumento era bom: tirava a peça mais alta
da placa — 2,90 mm, que fixava o teto sozinho — e, num pod envasado, fio
soldado segura melhor que trava. O que esse argumento não via é que a célula
que se **compra** já vem com dois fios e um plugue: com furos, montar o
aparelho significa cortar o plugue, soldar fio nu de 30 AWG dentro de uma
caixa de 20 mm e perder a possibilidade de trocar a célula. **Decisão do dono
em 2026-10-01:** o conector volta, e o pod paga os 0,5 mm de altura.

> [!IMPORTANT]
> **A polaridade é escolha deste projeto** e vai ao fabricante do pack
> antes da montagem: não existe padrão para conector de célula.

| Contato | Sinal | Direção | Observação |
|---|---|---|---|
| 1 | `VBAT+` | alim | o fio vermelho, na convenção usual |
| 2 | `GND` | alim | |

A célula é de **≥ 81 mAh com proteção própria** (a placa não tem proteção de
sobredescarga além do que o nPM1100 faz); o envelope reservado no pod é
**15 × 14 × 5,0 mm** — códigos `501415` ou `501414`
([12](12-comparacao-com-a-classe.md#a-célula-o-levantamento-nas-lojas-e-o-que-comprar)).

## J201 · Tag-Connect

**TC2030-IDC-NL**: seis pads de 0,7 × 0,6 mm a 1,27 mm de passo e três
furos de alinhamento, sem peça na placa. É a gravação de fábrica e a
bancada com a placa nua; dentro do pod fechado a depuração é pelo
conector magnético. Pinagem da ficha do Tag-Connect (o padrão ARM de 6
vias), em pé, com o `VTref` no `3V0`:

| Contato | Sinal | Direção |
|---|---|---|
| 1 | `VTref` (`3V0`) | alim |
| 2 | `SWDIO` | bidir |
| 3 | `nRESET` | entrada |
| 4 | `SWDCLK` | entrada |
| 5 | `GND` | alim |
| 6 | `SWO` | — (não ligado) |

## J301 · Furos da ponte

Cinco furos metalizados de 0,9 mm em ilhas de 1,5 mm, a 2,0 mm de passo,
na borda de baixo da placa, sob o conversor. Os fios sobem do braço pelo
rasgo no fundo do pod e entram nos furos por baixo; a solda no furo é o
alívio de tração ([07](07-pod.md#os-fios-da-ponte)).

| Furo | Sinal | Vai para |
|---|---|---|
| 1 | `E+` | `3V0_EXC`: a excitação, também `REFP0` do ADS1220 |
| 2 | `S+` | `R301` 1 kΩ → `AIN0` |
| 3 | `S−` | `R302` 1 kΩ → `AIN1` |
| 4 | `E−` | `GND` (o retorno da ponte e `REFN0`) |
| 5 | `SH` | `GND`: a blindagem do cabo, se houver |

A ordem `E+ S+ S− E−` é a ordem das cores usuais dos cabos de célula de
carga (vermelho, verde, branco, preto), para que quem for soldar não
precise de tabela.

Com a ponte escolhida, o **S5229**, que é ponte completa numa peça só
([01](01-lista-de-componentes.md#a-peça-achada-no-databook-do-fabricante-2026-09-28)),
**quatro** destes cinco furos são terminais do extensômetro: as duas
pontas da excitação e as duas do sinal. O quinto é a blindagem do cabo,
que não é terminal de grade nenhuma; fica onde está porque é por ali que
o cabo entra. Os cinco furos permanecem: a blindagem vale o furo, e o
padrão de 2,0 mm em cinco ilhas ocupa 10 mm de borda que a placa já tem.

## Pontos de teste

Pads de 1,0 mm **na face de trás**, para a bancada com a placa nua: no
pod a célula encosta nessa face e nada é alcançável além do conector
magnético. Cada um fica junto do que mede, pela tabela `JUNTO` de
[`cad/make_pcb.py`](cad/make_pcb.py).

| Ponto | Sinal | Junto de | Para quê |
|---|---|---|---|
| TP101 | `VBUS` | J101 | o 5 V do cabo chega? |
| TP102 | `VBAT` | J102 | a tensão da célula |
| TP103 | `3V0` | U101 | o buck |
| TP104 | `GND` | U101 | a referência da ponta de prova, com via própria ao plano |
| TP201 | `UART_TX` | U201 | o console do firmware |
| TP202 | `UART_RX` | U201 | |
| TP301 | `3V0_EXC` | U302 | a excitação da ponte chaveando |

## O que falta conferir

- **o conector magnético inteiro**: fornecedor, passo, corrente, altura,
  footprint, e se a peça escolhida aceita a numeração acima;
- a polaridade do `J102` com o fabricante do pack;
- a tabela `PADS_HOLYIOT` num módulo real, que decide se os pads 4
  (`SWDIO`), 5 (`SWDCLK`) e 1 (`NRESET`) do módulo são os que o `J201`
  alcança. Ela saiu do desenho mecânico do anúncio, não de uma ficha.

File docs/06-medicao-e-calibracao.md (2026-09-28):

# Medição e calibração

Como o módulo transforma a deformação do braço do pedivela em watts, e como cada constante do caminho é obtida e mantida. Todas as fórmulas daqui são as que o firmware implementa em `zephyr_app/src/model/`, com testes de host.

**Nesta página:** [Da ponte ao torque](#da-ponte-ao-torque) · [Amostragem](#amostragem) · [Ângulo e cadência](#ângulo-e-cadência) · [Potência por volta](#potência-por-volta) · [Calibração](#calibração) · [Temperatura](#temperatura) · [Orçamento de erro](#orçamento-de-erro) · [Saúde do sensor](#saúde-do-sensor) · [Referências](#referências)

## Da ponte ao torque

A ponte completa de quatro grades, duas esticando e duas comprimindo, entrega uma tensão diferencial proporcional à deformação, com a temperatura e as forças fora do eixo canceladas [1, 2.1.4]. Medida de forma ratiométrica, com a excitação da ponte na referência do conversor, o código de saída é proporcional a ΔR/R e independe da tensão de excitação [1, 3.1]:

```mermaid
flowchart LR
    F["Força no pedal F"] --> E["Deformação ε = k1 · F"]
    E --> V["Vout = Vexc · GF · ε"]
    V --> C["Código = 2^23 · ganho · Vout / Vref"]
    C --> T["τ = s · (código − zero)"]
```

Com `Vref = Vexc`, o código não depende de `Vexc`, e o firmware trabalha com uma única constante de inclinação `s` (N·m por contagem) e um zero, ambos calibrados:

`τ = s(T) · (c − c0(T))`

onde `c` é o código do ADS1220 (24 bits, complemento de dois, PGA 128), `c0` o zero e `s` a inclinação, os dois corrigidos pela temperatura `T` da ponte ([Temperatura](#temperatura)).

### Cisalhamento ou flexão: o padrão especificado está errado

A lista de componentes especifica **padrão de cisalhamento a 45°**, que é o padrão de torquímetro de eixo. O braço do pedivela não é um eixo: é uma viga em balanço carregada na ponta pela força tangencial do pedal. Numa seção a `d` do pedal existem duas coisas, e elas moram em lugares diferentes da mesma face:

- a **flexão**, no plano de rotação, cuja deformação é máxima junto das duas **bordas** da face e **zero no meio**;
- o **cisalhamento**, cuja deformação é máxima **no meio** da face, que é a linha neutra da flexão, e zero nas bordas.

Com números representativos, braço de alumínio, seção de 20 × 14 mm, 500 N de força tangencial e a grade a 60 mm do pedal:

| Onde | Deformação | Saída da ponte cheia a 3 V |
|---|---|---|
| Grade a 45° no meio da face (cisalhamento) | 52 µε | 0,31 mV |
| Grade axial junto da borda (flexão) | 459 µε | 2,76 mV |

**A flexão dá 8,9 vezes mais sinal**, e é ela que corresponde aos "1 a 3 mV" e às "algumas centenas de µε" que esta própria página já dizia: os números do documento descrevem flexão, e o padrão especificado é de cisalhamento. Os dois não podem estar certos ao mesmo tempo.

Pior que o sinal menor é a fragilidade: o cisalhamento só é máximo **exatamente** na linha neutra, e a poucos milímetros dela entra flexão, que é nove vezes maior. Uma colagem 2 mm fora do lugar contamina a leitura com o sinal que se queria evitar. Célula de carga de cisalhamento funciona porque a peça é usinada com alma fina, onde o cisalhamento domina; um braço de pedivela não tem alma.

**Recomendação: ponte cheia de flexão**, quatro grades alinhadas com o eixo do braço, duas junto de cada borda da face interna, em braços opostos da ponte. Assim a flexão no plano de rotação soma, e a flexão lateral (a força do ciclista para dentro), a força axial e a temperatura cancelam, porque afetam as quatro grades com o mesmo sinal. O argumento clássico contra a flexão, que a saída depende de onde a carga é aplicada, não vale aqui: a carga está sempre no eixo do pedal, e a distância só entra na inclinação, que a calibração de cada unidade absorve.

**O que isso puxa junto era decisão de compra, e foi tomada em 2026-09-28:** a resistência. Padrões de ponte cheia num único filme, que é o que elimina o erro de alinhamento entre quatro colagens separadas, existem principalmente em 350 Ω e 1000 Ω — mas o databook de classe transdutor do fabricante (2622-EN) traz também os de **alta resistência**, até 10 kΩ, e é de lá que sai o **S5229 de 5 kΩ**, designação `N2K-13-S5229A-50C/DG/E3` ([`hardware_powermeter/01`](../hardware_powermeter/01-lista-de-componentes.md)). A 5 kΩ a ponte drena 0,6 mA em vez de 3,0, e com o modo duty-cycle do conversor o aparelho inteiro fica em **0,68 mA** ([02](02-hardware.md#orçamento-de-consumo)). O S5229 é **ponte de Poisson**, não de flexão pura: duas grades longitudinais e duas transversais, o que num campo de flexão dá cerca de dois terços da saída de uma ponte de flexão e ainda assim seis vezes a de cisalhamento. Em 1000 Ω a alternativa específica para viga em flexão é o **S5067**, e aí o total vai a 1,40 mA.

**Escala.** A 200 W e 90 rpm o torque médio é 21 N·m; o pico numa pedalada forte passa de 100 N·m. Com extensômetros de fator 2 num braço de alumínio, a deformação de trabalho fica na casa de algumas centenas de µε, ou seja, 1 a 3 mV de saída da ponte a 3,0 V. Com ganho 128 o fundo de escala do conversor é ±23 mV, então sobra margem para o pico e para o zero deslocado pela colagem. A resolução sem ruído do sistema se calcula como em [1, 5.2.2]: com 2 mV de faixa útil e 1,6 µV pico a pico de ruído a 175 SPS (SBAS501D), são 2 mV / 1,6 µV ≈ 1250 contagens sem ruído por amostra, 0,08 % do fundo de escala, antes da média da volta, que divide isso por mais de dez.

## Amostragem

| Parâmetro | Valor | Motivo |
|---|---|---|
| Taxa da ponte | 175 amostras/s, modo normal do ADS1220 | a 120 rpm são 2 voltas/s, 87 amostras por volta; a pedalada tem conteúdo até cerca de 10 vezes a cadência (20 Hz), longe dos 87 Hz de Nyquist |
| Filtro | o sinc do próprio conversor; mediana de 3 contra pulsos; **nenhum passa-baixas** além disso | um passa-baixas achata o pico de torque e muda a média da volta por pouco, mas muda a efetividade e a suavidade por muito |
| Excitação | ligada 1,5 ms antes de cada conversão, desligada no DRDY | o TPS22916 liga em microssegundos; o filtro RC de entrada (datasheet do ADS1220, 9.1.2) assenta em menos de 1 ms |
| Acelerômetro | 100 Hz, ±4 g, modo normal, OSR 0 | o vetor gravidade gira a 2 Hz no máximo; 100 Hz dão 50 pontos por volta para o ângulo; ±4 g cobre a aceleração centrípeta (ω²r com r de 50 mm a 200 rpm é 22 m/s², 2,2 g) |
| Temperatura | 1 Hz | a ponte muda de temperatura em minutos, não em segundos |
| Relógio | uptime do kernel, 1 ms; eventos de volta com resolução de 1/1024 s como o BLE pede | |

Os dois fluxos (ponte e acelerômetro) são carimbados com o mesmo relógio e casados pelo carimbo, não pela ordem de chegada.

## Ângulo e cadência

O acelerômetro está fixo ao braço, no plano de rotação; qual eixo do encapsulamento é o radial e qual é o tangencial é um fato da placa, com o requisito e o elo que ainda falta medir em [02](02-hardware.md#orientação-do-acelerômetro). Os dois eixos no plano leem a gravidade girando mais os termos do movimento:

```latex
a_t = g\,\sin\theta + \alpha r, \qquad a_r = g\,\cos\theta + \omega^{2} r
```

com `θ` o ângulo do braço a partir da vertical, `r` a distância do sensor ao eixo, `ω` a velocidade angular e `α` a aceleração angular. O firmware (`crank_angle`) tira cada grandeza do eixo que é limpo para ela. A velocidade angular vem dos **cruzamentos de zero de `a_t`**, que acontecem no alto e no baixo da pedalada seja qual for o termo centrípeto: meia volta entre dois cruzamentos, com o instante de cada cruzamento interpolado entre as duas amostras em volta dele (a 100 Hz, sem interpolação, a quantização sozinha dava ±3 % a 90 rpm). O ângulo vem de `atan2(−a_t, a_r − ω²r)` com esse `ω`; quando `ω` muda num cruzamento, o ângulo da amostra anterior é recalculado com o `ω` novo, para que o `Δθ` que a potência integra não pule. Um cruzamento distingue alto de baixo pelo sinal do eixo radial corrigido e o sentido pelo lado por que `a_t` cruzou; a volta é o baixo passado para a frente; pedalar para trás dá `ω` negativo e nenhuma volta. Histerese de 0,5 m/s² arma um cruzamento; dois cruzamentos mais próximos que o pedivela mais rápido permite (`π/ω_max`) são ruído; 2 s sem cruzamento é `ω = 0`. A cadência é `60·ω/2π`; o tempo do evento vai em 1/1024 s ao rádio. Antes desse estimador, o `ω` era a derivada de `θ`: a derivada do `atan2` carregava o erro do termo centrípeto para dentro de `ω`, e a 100 Hz o teste sintético a 90 rpm devolvia 4 voltas em 10 s.

Regras de validade: uma amostra que implicaria `|Δθ/Δt| > 25 rad/s` (240 rpm) é descartada inteira e o ângulo anterior fica; parado quando o módulo da aceleração fica dentro de ±10 % de `g` por 2 s e `ω` abaixo de 0,3 rad/s; enquanto parado, nenhuma volta é publicada e o zero pode ser revisto ([Calibração](#calibração)). A posição do sensor `r` entra na configuração e é medida na placa, não estimada.

## Potência por volta

A potência é a média, na volta, do produto torque × velocidade angular:

```latex
P = \frac{1}{T}\int_{0}^{T}\tau(t)\,\omega(t)\,dt \approx \frac{1}{T}\sum_{i}\tau_i\,\Delta\theta_i
```

Somar `τ_i Δθ_i` (o trabalho por amostra) e dividir pelo período é o que faz a estimativa não depender de a cadência variar dentro da volta, que ela varia: o torque cai perto dos pontos mortos e a velocidade angular junto [3]. Numa volta com 87 amostras a soma é a integral por retângulos, com erro de segunda ordem.

| Grandeza | Como sai da volta | Unidade que o rádio usa |
|---|---|---|
| Potência instantânea | `P` acima; com um lado só, `2·P` | W |
| Torque acumulado | soma de `τ_médio · 1` por volta | 1/32 N·m |
| Energia acumulada | soma de `P · T` | kJ |
| Voltas e tempo do último evento | contador e carimbo | 1/1024 s |
| Balanço esquerda/direita | 50 % declarado, "referência desconhecida", com um lado só | % |
| Efetividade do torque | `(W⁺ + W⁻) / W⁺ · 100`, com `W⁺` o trabalho dos trechos de torque positivo e `W⁻` o dos negativos (negativo) | % |
| Suavidade da pedalada | `P_média / P_pico · 100` na volta | % |

As duas últimas são as definições que os dois protocolos usam; a literatura chama a primeira de índice de efetividade da força e mede o mesmo trabalho útil sobre o total [4, 5]. Com um lado só, dobrar a potência assume simetria; a assimetria entre as pernas medida em ciclistas fica em geral abaixo de 5 % e cresce com a intensidade [6], o que entra no orçamento de erro.

## Calibração

Três constantes, três procedimentos, todos disparados pelo BLE ([05](05-protocolos.md)) e conduzidos pela tela do ciclocomputador ou por um app:

1. **Zero** (`c0`). Braço na vertical, sem carga, módulo parado. O firmware exige estabilidade: 64 amostras com desvio padrão abaixo de 4 contagens e média fora de ±20 % do fundo de escala (senão a ponte está aberta, em curto ou saturada). O zero também é revisto sozinho a cada parada de mais de 5 s, com a mesma regra, e só substitui o anterior se mudou menos que um limite configurado (auto-zero conservador): uma parada com o pé no pedal não pode virar zero.
2. **Inclinação** (`s`). Braço na horizontal, massa conhecida `m` pendurada no eixo do pedal, a `L` do centro do eixo: `τ = m · g · L · cos φ`, com `φ` o desvio da horizontal medido pelo próprio acelerômetro. Três a cinco massas (5 a 20 kg) e um ajuste por mínimos quadrados de `τ` contra `c − c0`; o firmware devolve a inclinação, o resíduo máximo e a histerese (subida contra descida). Resíduo acima de 0,5 % ou histerese acima de 0,3 % reprovam a colagem, não o firmware. É o método estático de calibração de células de carga [7, 8], aplicado com o braço como célula.
3. **Temperatura**. Zero e inclinação repetidos em três ou mais temperaturas entre −10 e 50 °C (câmara, congelador, sol), lidas pelo TMP117 junto da ponte; o ajuste dá `c0(T)` de segunda ordem e `s(T)` de primeira ([Temperatura](#temperatura)).

A verificação é a prova de estrada: rolo e rua contra um medidor de referência, por semanas, comparando potência média por intervalo e a distribuição da diferença; o critério da fase 1 é ±2 % na média de 1 minuto.

## Temperatura

A ponte completa cancela a dilatação comum das quatro grades, mas sobram o coeficiente do adesivo, a diferença entre a dilatação do alumínio e a compensação do extensômetro, a deriva do próprio conversor e a mudança do módulo de elasticidade do braço com a temperatura [1, 4.7; 2]. O modelo do firmware:

```latex
c_0(T) = c_0 + k_1\,(T - T_0) + k_2\,(T - T_0)^2, \qquad s(T) = s\,[1 + k_3\,(T - T_0)]
```

com `T0` a temperatura da calibração de inclinação. Os coeficientes vêm do procedimento 3; sem eles o firmware usa `k = 0` e declara na característica de recursos que a compensação não está calibrada. O sensor de temperatura interno do ADS1220 (0,5 °C) serve de reserva se o TMP117 faltar.

## Orçamento de erro

Contribuições na potência, a 200 W, estimadas como incertezas-padrão e somadas em quadratura, no espírito do guia GUM [9]:

| Fonte | Contribuição | Como se reduz |
|---|---|---|
| Massa de calibração | 0,1 % (massa aferida) | balança de referência |
| Comprimento do braço `L` | 0,3 % (0,5 mm em 172,5) | medir com paquímetro; gravar na configuração |
| Ângulo na calibração | 0,1 % (cos φ com φ < 2,5°) | o acelerômetro mede φ |
| Resíduo da temperatura | 0,5 % (residual depois da curva) | mais pontos de temperatura |
| Ruído do conversor | < 0,05 % na média da volta | nenhum |
| Tempo da volta | 0,1 % (1/1024 s em 0,67 s) | nenhum |
| Fluência da colagem | 0,3 % | AE-10, cura completa, verificação periódica do zero |
| Assimetria das pernas (um lado só) | 2 a 5 %, sistemático por ciclista | dois módulos (fase 1b) |
| **Total sem assimetria** | **≈ 0,7 %** | |

O que decide os ±2 % da fase 1 é, portanto, a assimetria, que o produto de um lado só não corrige; a medição em si tem margem.

## Saúde do sensor

Verificações contínuas, publicadas nas características de estado e no log:

As regras são as do módulo `health`, cada uma com o seu flag; as quatro primeiras e a última **param a medição** (nenhuma potência é publicada), as outras são avisos:

| Flag | Regra | Para? |
|---|---|---|
| `BRIDGE_OPEN` | código em ±80 % do fundo de escala ou além, com a excitação ligada (entrada no trilho: ponte aberta ou saturada) | sim |
| `BRIDGE_STUCK` | o mesmo código por 2 s com a excitação ligada (ponte em curto ou entrada presa) | sim |
| `EXCITATION` | a referência lida pelo monitor interno do ADS1220 fora de 3,0 V ± 10 % | sim |
| `IMU_STALE` | acelerômetro sem amostra por 500 ms | sim |
| `NOT_CALIBRATED` | inclinação desconhecida | sim |
| `IMU_RANGE` | módulo da aceleração fora de 0,5 a 6 g por mais de 1 s | não |
| `TEMP_RANGE` | temperatura da ponte fora de −20 a 70 °C | não |
| `ZERO_DRIFT` | zero em uso mais longe do zero da calibração que o passo do auto-zero: aviso de recalibrar | não |

Com a excitação desligada nada da ponte é julgado (o código de uma ponte sem excitação é zero, sã ou não): o que se lê nesse estado é o ruído do conversor, e é o monitor da referência que diz se a excitação existe.

## Referências

1. TEXAS INSTRUMENTS. *A Basic Guide to Bridge Measurements*, nota de aplicação SBAA532A. Seções 2.1.4 (ponte com quatro elementos ativos), 3.1 (medição ratiométrica), 4.7 (deriva), 5.2.2 (contagens sem ruído), 5.5 (calibração de offset e ganho). [ti.com/lit/an/sbaa532a/sbaa532a.pdf](https://www.ti.com/lit/an/sbaa532a/sbaa532a.pdf)
2. MICRO-MEASUREMENTS. *Stress Analysis Gage Reference Guide*: seleção de série, autocompensação térmica, resistência de 1 kΩ, adesivos M-Bond 200 e AE-10, proteções. [docs.micro-measurements.com/?id=18236](https://docs.micro-measurements.com/?id=18236)
3. *Interpretation of crank torque during an all-out cycling exercise at high pedal rate*. Sports Engineering, 2010. [doi:10.1007/s12283-010-0051-2](https://doi.org/10.1007/s12283-010-0051-2)
4. *Effect of Gear Ratio and Cadence on Gross Efficiency and Pedal Force Effectiveness during Multistage Graded Cycling Test Using a Road Racing Bicycle*. Sports, 2022. [doi:10.3390/sports11010005](https://doi.org/10.3390/sports11010005)
5. *Within- and between-session reliability of a pedal force system for power output and pedal force effectiveness measurements*. Human Movement, 2020. [doi:10.5114/hm.2020.94197](https://doi.org/10.5114/hm.2020.94197)
6. *Effects of Exercise Intensity on Pedal Force Asymmetry during Cycling*. Symmetry, 2021. [doi:10.3390/sym13081449](https://doi.org/10.3390/sym13081449)
7. NIST. *Automation of strain-gauge load-cell force calibration*, NISTIR 4823, 1992. [doi:10.6028/nist.ir.4823](https://doi.org/10.6028/nist.ir.4823)
8. BSI. *Force measurement. Strain gauge load cell systems. Calibration method*. [doi:10.3403/02919794](https://doi.org/10.3403/02919794)
9. JCGM 100:2008. *Evaluation of measurement data. Guide to the expression of uncertainty in measurement (GUM)*. [bipm.org](https://www.bipm.org/en/committees/jc/jcgm/publications)
10. *Determining the Stress Distribution in a Bicycle Crank Under In-Service Loads*. Experimental Techniques, 2015. [doi:10.1111/ext.12141](https://doi.org/10.1111/ext.12141): onde o braço deforma sob carga de pedalada, o que orienta a posição dos extensômetros.
11. TEXAS INSTRUMENTS. *ADS1220 datasheet*, SBAS501D. Bluetooth SIG, *Cycling Power Service 1.1*. Bosch, *BMA400 datasheet* BST-BMA400-DS000-14.

Os artigos 3 a 6 e 10 foram localizados pelo Crossref em 2026-09-27 (título, revista, ano e DOI conferidos); o texto completo não foi lido nesta sessão, e as definições usadas acima são as dos protocolos e das notas de aplicação.

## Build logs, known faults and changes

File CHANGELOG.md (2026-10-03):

# Changelog

Formato do [Keep a Changelog](https://keepachangelog.com/pt-BR/1.1.0/); versões pelo [SemVer](https://semver.org/lang/pt-BR/).

## [Não lançado]

### Fechado em 2026-09-28

- **A placa está roteada com 0 erros de DRC.** 440 segmentos, 153 vias, 75 ligações; 25 avisos, todos de registro de biblioteca, porque os footprints deste projeto são gerados. Ficam **3 ligações de sinal** sem cobre (`I2C_SCL`, `SPI_MOSI`, `SPI_SCK`, as três no mesmo trecho) e 4 vias de costura do plano de terra, que o plano resolve. O estágio de congestão negociada rodou as 160 rodadas e foi **recusado**: ele chega a zero célula disputada só com 62 a 64 ligações, contra as 75 do sequencial.
- **Dry run da placa: 14 regras cumpridas, 5 violadas, 5 não mensuráveis.** Dry run do pod: **17 cumpridas, 1 violada** — a `PD17`, que é um requisito sobre a **bicicleta** e só sai com um paquímetro. As 15 vistas, os PDF da placa, da montagem e do pod e os dois STL foram regerados.
- **A verificação inteira do projeto rodou três vezes com resultados idênticos** (`python tools/verificar_tudo.py`): esquemático, contorno, placa, os dois dry runs, o mapa de pinos, os 26 diagramas, os 388 links, os 134 casos de teste de host e os dois builds de firmware.

### Medido

- **As quatro imagens da placa estavam velhas, e o conector não aparecia nelas.** Elas eram de antes de tudo: o `make_3d.py` e o `montagem.py` não tinham sido rodados depois da troca do `J102`. Regerados — e, de quebra, o `04-placa.md` e o `README.md` ainda traziam **47 × 14 mm** de placa e **55,7 × 19,0 × 10,0 mm, 13,3 g** de pod, de um desenho anterior a tudo isso.

- **E o conector deixou de ser um tijolo: ele é desenhado peça a peça, com a BOCA aberta.** A biblioteca do KiCad 8 não traz modelo 3D do `SM02B-SRSS-TB`, então o que havia era a caixa de 4,00 × 4,25 × 2,90 que o gerador faz para footprint sem modelo. O motivo de desenhar não é estético: **a propriedade que importa deste conector é para onde a boca aponta**, e uma caixa não mostra isso — agora dá para conferir no 3D, a olho, que ela encara a baía da célula. São nove formas: parede de fundo, duas laterais, piso, teto, os dois contatos dourados no passo de 1,0 visíveis pela abertura, e as duas unhas de fixação. A abertura foi **medida**, não olhada: nenhuma forma cruza a faixa z 0,55 a 2,35 no meio da face +Y.

- **O conector da célula voltou, e é um JST SH de entrada lateral** (`SM02B-SRSS-TB`, 2 vias, 1,0 mm, boca paralela à placa). Ele tinha virado dois furos metalizados em 2026-09-26, para tirar da placa a peça mais alta; o que esse argumento não via é que a célula que se **compra** já vem com dois fios e um plugue, e com furos a montagem vira cortar o plugue e soldar fio nu de 30 AWG dentro de uma caixa de 20 mm, com a célula deixando de ser trocável. O teto da tampa sobe de 2,7 para 3,2 e o pod de 7,2 para **7,7 mm**.

- **As três séries foram postas na placa e o pod foi medido com cada uma**, em vez de escolhidas por intuição:

  | | altura | planta | pod | massa | regras |
  |---|---|---|---|---|---|
  | PH 2,0 `S2B-PH-SM4-TB` | 4,85 mm | 5,9 × 7,6 | 9,70 | 17,7 g | 24 de 32 |
  | GH 1,25 `SM02B-GHS-TB` | 4,24 mm | 5,8 × 5,0 | 9,04 | — | — |
  | **SH 1,0 `SM02B-SRSS-TB`** | **2,90 mm** | 4,3 × 4,0 | **7,70** | **14,5 g** | **30 de 32** |

  O PH é o que as células de bolsa trazem de fábrica — confirmado em três peças documentadas (Adafruit 1570 e 1769, SparkFun 40 mAh) — e por isso foi tentado primeiro. A conta dele não fecha: além dos 2 mm de altura e dos 3,2 g, ele obriga a trocar o **conector magnético** por um de 5,35 mm (o lugar reservado tem 3,2), alarga o canal em 1,8 mm para o plugue caber, deixa a cabeça dos parafusos 1,1 mm acima do alvo de altura, leva o furo cego do parafuso a 5,5:1 e põe a pilha cola + pod em **10,2 mm contra os 10,0 de folga de quadro** que o projeto reservou — o aparelho deixaria de caber entre o pedivela e o quadro. Com SH nada disso acontece, e o preço é **uma linha no pedido da célula**: os fabricantes vendem o conector como opção.

- **A cadeia de alturas passou a sair de um lugar só** (`footprints.py`): conector da célula → teto da tampa → altura exigida do conector magnético. Os três números estavam escritos separados, e os três envelheceram em sequência — a parede do pod ficou em 2,0 depois que o cordão do anel O já podia ser menor, o teto ficou em 2,7 depois que o conector voltou, e a altura exigida do conector magnético ficou em 3,20 depois que o teto mudou. Nos três casos o número velho era uma **cópia** de um número que tinha se mexido.

- **O parafuso esquerdo saiu da linha de centro.** Ele dividia o canal com os fios da célula, o que funcionava enquanto ali passavam dois fios nus de 0,9 mm; com o plugue, o ressalto de 3,4 ficava bem na frente dele — 11,1 mm³ de fio dentro da concha, 9,3 do plugue e **0,00 mm de curso para encaixar**. E o `J102` andou 0,2 mm para dentro da placa, porque em 3,5 o curso livre era 1,80 contra os 2,00 que o encaixe pede: um décimo de conector para dentro é um décimo de corredor a mais, e não custa milímetro nenhum de pod.

- **Regra nova, `PD32`: o plugue tem de ter por onde ENTRAR, e não só por onde ficar.** Ela mede, no sólido da concha, o curso livre do plano da boca ao longo do eixo de encaixe. Um conector emparedado cabe e não monta, e nenhuma regra via isso.

- **A placa rotea com 0 erros de DRC e para em 2 ligações sem cobre (`CHG_N` e `VBAT`), e quatro hipóteses foram testadas e refutadas** antes de eu parar. Esforço do roteador (100 e 500 passagens, ~40 passadas): empata. Posição de peça (três lugares para o furo de fixação, dois para o `J102`): empata, e o furo em (34; 12) piora para 12 erros e 3 em aberto. **Fuga de pad** — a hipótese que mais parecia, porque foi o gargalo real da rodada anterior: refutada por medida, com o `medir_fuga.py` novo, que varre um anel em volta de cada pad e pergunta ao `route.via_cabe_aqui` se cabe via; os 13 pads das redes em aberto têm lugar, vários a 0,5 mm. E a folga inflada do DSN: refutada para o roteamento. O que sobra e não foi medido é se existe **corredor livre** entre as duas ilhas de cada rede — `CHG_N` precisa de 25 mm, e o `fechar_ultimas.py` tem raio de busca de 5: ele é a ferramenta do último milímetro, não a deste caso.

- **A folga que o DSN pede ao roteador estava inflada em toda regra, e agora só nas que envolvem via.** Os 115 µm existem por causa do **furo** da via — e só via tem furo. Pedir 115 entre duas trilhas e entre trilha e ilha apertava todo corredor da placa em 26 µm por lado sem comprar nada: o passo por trilha caía de 0,179 para 0,205 mm, cerca de 15 % menos trilhas por canal. Agora as regras com via continuam em 115 e as outras vão para os **88,9** que o fabricante aceita e o DRC cobra. Não destravou as duas redes, mas pedir folga que ninguém exige era errado de qualquer forma, e a placa continua com 0 erros de DRC depois da mudança.

- **O `limpar_curtos.py` ganhou um caso novo, com condição: `clearance` quando o culpado é uma trilha de GND.** `clearance` estava fora da lista de propósito — ela é quase sempre dois vizinhos legítimos perto demais, e apagar um dos dois é exagero. Mas GND tem **plano**, e o plano refaz a trilha: apagar uma trilha de GND que roça num pad vizinho não tira ligação nenhuma. Foi o que levou a placa de 2 erros para **0** em 2026-10-01 (duas trilhas de GND a 0,0840 mm do pad do `D101`, contra os 0,0889 da classe).

- **A placa do repositório não era mais reprodutível pelo próprio gerador, e ninguém sabia.** A reserva do furo de fixação tinha passado a invadir o courtyard do conector magnético em 2,65 × 0,45 mm e o colocador não conseguia mais pôr o `J101` em lugar nenhum — mas a verificação do projeto rodava o `check_pcb` e o `dry_run_pcb` **sobre o arquivo**, nunca sobre o gerador. O furo foi para a linha de centro da placa (30,5; 8,0), onde livra o conector por 0,55 mm e prende melhor, e **`make_pcb.py --conferir`** passou a existir: coloca sem gravar, e entrou na verificação do projeto como "a placa ainda é a que o gerador produz".

- **A parede do pod passou a SAIR da vedação, e com isso a largura fechou no alvo.** Ela era 2,0 mm porque o sulco do anel O precisa de 1,05 mais 0,5 de terra de cada lado — mas parede e sulco estavam escritos como dois números soltos, e **ninguém tinha ligado um ao outro**: a parede ficou em 2,0 depois que o cordão já podia ser menor. Agora `PAREDE = JUNTA_SULCO_L + 2 × JUNTA_TERRA`, e com cordão de **0,60** no lugar de 0,80 ela vai a **1,50** e a largura do pod a **20,00 exatos**, contra os 20,0 da face interna do braço. A `PD17` passa pela primeira vez; o pod vai a **73,5 × 20,0 × 7,2** e **13,4 g**. O cordão de 0,60 é requisito de compra, e se não for encontrado a saída é junta de face com parede de 1,2.

- **A `PD13` passou a medir o sulco com grade de 0,02 mm numa janela dele.** Com os 0,1 mm da grade do pod inteiro, um sulco de 0,45 saía medido como 0,50 — meio voxel de viés — e a compressão calculada dava 16,7 % num sulco que o desenho faz em 25,0 %. Medido fino, dá 23,3 %. Testado por mutação: sulco raso demais reprova com 56,7 % e "o anel não cabe quando esmagado".

- **Análise a fundo do que prende o comprimento** ([12](hardware_powermeter/12-comparacao-com-a-classe.md#a-fundo-o-que-prende-o-comprimento)), a pedido do dono. Empacotando os contornos de ocupação reais numa tira de 16 mm, as peças da **frente cabem em 31,0 × 16,0** (66 % de ocupação) e as do verso em 7,1 × 16; a placa tem **50 × 16 com 41 % de ocupação na frente**. Os 19 mm de diferença não são peças: são colocação, roteamento e área livre de antena. E o requisito que manda na célula **não é a pedalada**: 50 h a 0,68 mA pedem 34 mAh, mas **6 meses parado a 15 µA pedem 65,7** — é a guarda que fixa o piso em ~70 mAh.

- **A célula não cabe embaixo da placa como ela está, e o motivo é colocação.** O verso está **16 % ocupado**, 84 % livre, e mesmo assim o **maior retângulo livre mede 40,5 × 2,5 mm**: as 43 peças estão espalhadas. Agrupadas — elas empacotam em 7,1 × 16 — liberariam um bolso de ~18 × 14, e aí a célula embaixo levaria o pod de 73,5 para **54,0 mm** ao custo de 2,35 mm de altura. Com a placa recolocada para ~35 × 16 o pod chegaria a **39 × 20 × 9,55**, mas a guarda de 6 meses ficaria no fio.

- **A célula no varejo brasileiro: o levantamento ficou conclusivo, e a resposta é "não existe lá".** Seis lojas foram lidas com o catálogo aberto — Curto Circuito, Usinainfo, Baú da Eletrônica, Huinfinito, Eletrogate e Vida de Silício — e **nenhuma estoca bolsa LiPo pequena**: todas vendem pilha-botão, 18650, 9 V, suportes e carregadores TP4056, e nada entre isso. Outras duas (MakerHero e Solda Fria) e o Mercado Livre, inclusive a API pública dele, recusaram a conexão. Não é falha da busca: é um fato de mercado. Quem vende bolsa de 100 mAh no Brasil são os anunciantes de marketplace e os importadores, e o código de tamanho é o termo de busca.

- **O `401125` que estava na mão não serve mais, e não serviria mesmo que coubesse.** Ele é 4,0 × 11 × **25** e era a célula da case antiga, quando ela ficava sob a placa; a baía de hoje é 15 × 14 × 5,0 e o lado de 25 não entra em nenhuma das duas direções. Alongar a baía para aceitá-lo levaria o pod de 73,45 para **83,45 mm** em troca de **5 % de carga** (1.100 mm³ contra 1.050). Os códigos que cabem e fecham a guarda de 6 meses são **`501415`** (a baía inteira, 81 a 100 mAh) e **`501414`**; `501215` fica no fio e `401415` e `401214` ficam abaixo do piso.

- **E a pilha-botão que caberia, medida:** com a parede em 1,5 a cavidade tem 17,0 mm, então a **CR2032 do 4iiii não caberia no nosso pod** (20,0 de diâmetro) — mas uma **CR1632** (16,0 × 3,2, ~140 mAh) cabe e daria **206 h contra as 119 h de hoje**, por R$ 2 e em qualquer prateleira. Fica registrado como medida, não como proposta: ela acaba com a recarga e com o USB e o SWD pelo cabo, que foram decisão do dono em 2026-09-27.

- **A classe medida, pelo que ela publica** ([12](hardware_powermeter/12-comparacao-com-a-classe.md)). O **4iiii Precision 3+** publica 9 g, perfil de 5,5 mm, CR2032, até 800 h, ±1 %, IPx7 e **Apple Find My**; o **U2e V4** publica 20 g, Li-Po recarregável com carga por USB magnético, máximo de 52 h, ±2,5 % e IPX7. Nenhum dos dois publica as três dimensões. O U2e é o nosso par de arquitetura, e por todo número publicado o nosso desenho está à frente dele: **5,8 g mais leve, 2,3× mais autonomia e meio ponto melhor de precisão**. O 4iiii é outra arquitetura, e é contra ele que perdemos.

- **Por que somos mais compridos, medido.** Nossa placa é 50 × 16 = **800 mm²**; a da classe, pela fotogrametria, ~38 × 20 = **760 mm²**. É **a mesma área numa forma pior** (3,1:1 contra 1,9:1), com ocupação de 41 % na frente e 9 % no verso: não há gordura a cortar, há proporção a mudar. Dos 74,45 mm, 50 são a placa e 19,95 a célula ao lado. E o alvo de **38 × 20 não é alcançável com esta lista de peças**: com parede de 2,0 e folga de 0,5 ele dá uma placa de 33 × 15 = **495 mm²** contra os 800 que usamos. A maior economia que não custa capacidade é trocar o anel O de sulco por junta de face na tampa — libera 1,6 mm de largura e cerca de 28 mm de comprimento, chegando a ~46 × 21.

- **Por que temos menos autonomia, medido.** A CR2032 tem **0,224 mAh/mm³** contra **0,077** da nossa bolsa de LiPo: no mesmo volume (1.005 contra 1.050 mm³), **225 mAh contra 81**. Somado ao consumo (0,28 mA deles contra 0,68 nosso), dá os 6,7× de diferença entre 800 h e 119 h. Dos nossos 0,68 mA, **0,6 é a ponte de 5 kΩ sozinha, 88 % do orçamento**.

- **Apple Find My é viável, com três condições, e Samsung Find não é.** O 4iiii o anuncia, o que prova o caminho para fabricante pequeno — e ele passa pelo programa MFi. O anúncio BLE a cada 2 s **já existe** no nosso estado guardado, então o custo em autonomia é zero se ele puder ser o mesmo anúncio e **três meses de guarda** (de 7,4 para 4,4 meses) se tiver de ser outro. O bloqueio real é o **emissor de som** que a regra antiperseguição exige: o pod é envasado e acabamos de fechar as seis aberturas dele. A rede **Find My Device do Google** é mais acessível e cobre mais bicicletas no Brasil. A **SmartThings Find da Samsung não tem SDK de acessório**: não é viável. *Esta seção não pôde ser conferida em fonte primária — o orçamento de busca da sessão acabou — e está marcada como tal no documento.*

- **O envelope da célula estava velho nos documentos vivos.** Ela mudou para 15 × 14 × 5,0 (≈ 81 mAh) em 2026-09-30, quando saiu de baixo da placa, e `docs/01`, `docs/02` e a lista de componentes ainda diziam 23 × 11 × 4,0 e 78 mAh — inclusive a linha que é **requisito de compra**. Corrigido, com as horas da tabela de consumo recalculadas (119 h em vez de 114).

- **O pod passou a MEDIR o sólido desenhado, e com isso fecharam os sete bloqueantes da revisão de 2026-10-01.** Dez revisores mediram o pod e acharam sete interferências que o impediam de fechar; no mesmo commit o dry run dizia que **18 das 20 regras estavam cumpridas**. A causa era uma só: o desenho é uma sopa de triângulos, a classe `Malha` não sabia subtrair e não dava para perguntar a ela "este ponto está dentro?", então sete regras liam a **constante** que deveria ter gerado a geometria — e uma regra assim passa com a peça desenhada ou sem ela. `PARAF_PESCOCO_D = 2,00` estava declarado desde sempre, o ressalto saía em diâmetro cheio de 3,40 por um furo de 2,20, e nenhuma regra viu.

- **O que mudou na ferramenta.** A `Malha` registra cada primitiva na **mesma chamada** que emite os triângulos (`Malha.solidos` e `Malha.faixas`), então o registro não pode divergir da malha; o módulo novo `medir.py` rasteriza esse registro numa grade de voxels de 0,1 mm e lê as arestas dos STL; `regras_medidas.py` traz **dez regras novas** (`PD21` a `PD30`). A `Malha.caixa` passou a **recusar** caixa de lado não positivo, e pegou na primeira execução a cauda dos fios da célula desenhada de x 2,300 a x 2,000 — largura negativa, do lado oposto ao conector, dentro do corpo da própria célula.

- **Os sete bloqueantes.** (1) O pescoço de 2,00 do parafuso passou a ser desenhado, e a `PD14` o mede **por raio no sólido** dentro da faixa z da placa. (2) A aba da tampa virou quatro barras cortadas em tudo o que sobe na cavidade — ela entrava 5,565 mm³ na bolsa de lítio e 2,315 em três nervuras, o que fazia a tampa parar 1,00 mm alta e o anel O não comprimir nada. (3) Os dois fios da célula ganharam uma passagem de 3,4 mm cortada nas nervuras e no piso: a saída real era **0,000 mm**. (4) O colar do rasgo passou a ter altura **por barra**, 0,1 mm abaixo do que passa sobre ela, em vez de esmagar o R302 e o C304. (5) A vedação da janela virou uma junta plana no **ombro do conector**, comprimida 28,6 % por um ressalto da tampa, como `docs/02` pede desde sempre. (6) O lábio e o dreno saíram: o dreno ficava 0,50 mm **acima** do fundo do poço, com queda zero. (7) Os cinco fios da ponte ganharam bolso e canaleta na face de baixo: eles corriam até 44,83 mm dentro de uma linha de cola de 0,5 mm.

- **E os graves.** O relevo da base de colagem **acrescentava** duas caixas onde queria cavar (100 % das tiras externas era face maciça em z = 0; hoje a `PD23` mede 0,00 mm² onde havia 445,20). A célula ganhou reserva de inchaço de 0,5 mm e folga de 0,25 nos quatro lados, com a baía **cavada no piso** para isso não levantar o pod. O assento da placa foi de 0,100 para 0,500 mm por borda. O envase ganhou **nível** (0,4 abaixo do teto) e o pescoço do parafuso sobe acima dele, para a rosca não ficar em resina. O alvo de envelope passou de 60 para os **38 × 20 × 10** que `docs/02` pede desde 2026-09-27.

- **E o furo de luz do LED virou redondo.** Ele era um quadrado de 2,5 × 2,5 = 6,25 mm² onde o PDF desenhava e o texto anunciava um círculo de 2,5 = 4,91: 27 % a mais de área para a resina transparente encher, com o desenho dizendo uma coisa e o STL sendo outra. A chapa recebe agora um furo quadrado de 2,6 e um anel entre ele e um polígono de 16 lados devolve o círculo; a `PD9` mede 4,78 mm² **no sólido**. Na primeira tentativa o quadrado tinha o lado igual ao diâmetro, o círculo inscrito encostava nele nos quatro meios de lado e quatro quads saíam degenerados — a `PD26` pegou, "1 de 85 primitivas da tampa não fecham".

- **A meta-regra das constantes mortas estava sendo enganada pela própria documentação.** Ela contava ocorrências do nome no texto dos arquivos, e o `PARAF_CABECA_D` passava porque o nome dele aparece no comentário logo acima, citado como exemplo de constante morta. Contando **tokens de código** (`tokenize`), ela achou três: `PARAF_CABECA_D`, `PARAF_TAMPAO_P` e `PAREDE_VEDA`.

- **E a conta do tampão de resina nunca tinha sido feita.** Uma cabeça escareada M1,6 tem 0,96 mm de altura, 0,96 + 0,80 de tampão dão 1,76 contra os 1,00 de tampa, e um escareado de 3,20 não entra num furo de 1,90. Engrossar a tampa custaria altura em todo o pod por causa de dois pontos, e um ressalto na face de baixo bateria no colar do pescoço. O que fecha é uma **anilha vedante sob cabeça cilíndrica saliente**: peça de prateleira, comprimida 30 %, desenhada no conjunto e medida pela `PD31`, que também confere no sólido que a face da tampa sob ela é plana. O pod chega a 8,65 mm nos dois parafusos, contra o alvo de altura de 10. E o `PAREDE_VEDA` passou a ser uma condição que o módulo verifica ao carregar, em vez de um número solto.

- **Cada regra nova foi testada por mutação:** o defeito volta ao gerador e a regra tem de reprovar. Conferidas em 2026-10-01: aba fechada → `PD21` acusa 2 pares; corte da passagem removido → `PD22` diz que não passa fio de 0,90; relevo acrescentado → `PD23` acusa 302,7 mm²; ressalto da junta removido → `PD24` diz "comprimida 0,0 %"; canaleta de 0,2 → `PD25` acusa 96,7 mm² sem cola, e canaleta nenhuma → "não mede nada"; pescoço em diâmetro cheio → `PD14` acusa 3,40 contra 2,20, e sem pescoço → "não há sólido nenhum".

- **Estado do pod:** 74,5 × 21,0 × 7,2 mm, 14,2 g estimados, **28 regras cumpridas e 3 violadas**. As três são decisões do dono, não defeitos: a `PD6` mede o braço de alumínio 4,0 mm abaixo da antena (a ficha do ME54BS13 pede 3 a 5 mm: faixa de risco, a medir na bancada), a `PD10` mede 74,5 × 21,0 contra 38 × 20, e a `PD17` mede 21,0 de largura contra os 20,0 do pior caso da classe. **Nada foi impresso nem montado.**

- **A placa está roteada por inteiro** (2026-10-01): **838 trilhas, 221 vias, 0 erros de DRC e 0 ligações em aberto**, contra 21 em aberto no dia anterior. As 52 violações que restam são todas avisos conhecidos — 44 de registro de biblioteca (os footprints deste projeto são gerados), 7 de biblioteca e 1 de serigrafia na borda. O `RT1` cumpre pela primeira vez; o `GN1` diz que as 49 ilhas de terra de superfície estão ligadas, 42 delas por via própria ao plano interno; o `GN2`, 73 vias na borda com vão máximo de 3,0 mm. Dry run da placa: **16 regras cumpridas e 4 violadas**, contra 14 e 6.

- **O que fechou foi a ordem, não a ferramenta** (decisão do dono: "uma de cada vez, em vez de tudo de uma vez"). A costura do terra passou a rodar **antes** do roteador, na placa vazia onde toda via cabe — rodando depois, 105 dos 112 itens dela ficavam perto demais do cobre do roteador e eram removidos, levando junto a costura da borda (`GN2` acusava "não há costura"). Só a troca de ordem levou de 15 para 2 em aberto.

- **E isso só foi possível depois de descobrir que o DSN aceita cobre.** Duas tentativas anteriores de pôr cobre antes do roteamento davam um `.ses` de **zero byte**, e a conclusão da época — "o DSN tem de vir limpo" — estava errada: o que quebrava era a **interface gráfica** do Freerouting estourando ao desenhar o nosso despejo. Sem interface e sem despejo, ele lê placa com cobre e grava a sessão normalmente.

- **O refino, uma passada de cada vez.** Rotear, medir, tirar o que o **fabricante** reprova, medir de novo, repetir. O `limpar_curtos.py` apaga por UUID só as trilhas que o DRC do KiCad chama de curto — ilha e via ficam — e só abaixo de 0,0889 mm: a nossa `conferir` é de propósito mais estrita, e remover tudo o que ela acusa foi o que custou a costura.

- **As últimas, uma a uma** (`fechar_ultimas.py`), cada uma pelo que é: via quando as pontas estão em camadas diferentes, toco quando estão na mesma, e via ao lado do pino quando a outra ponta é o despejo. O toco parte da **borda** do pad e pode **virar** (reto, L ou L de 45°): as duas ilhas de terra do módulo ficam em x = 45,95 e a faixa da antena começa em 45,70, então o centro delas está dentro e a metade esquerda está fora, e havia 2.271 lugares bons para a via em volta da ilha 36 sem nenhum alcançável em linha reta.

- **A última ligação da placa foi fechada por três correções somadas** (2026-10-01): o `reparar.py` passou a julgar um conserto pelo que ele **acrescenta** (comparando o total, recusava um caminho perfeito porque a placa já carregava 62 pares que só a nossa medida acusa), a julgar pela **folga do fabricante** (recusou por um par a 0,136 mm que pedia 0,14 — quatro milésimos, a 40 mm do conserto), e a desenhar a amarração de terra encaixotada com **largura de sinal** em vez dos 0,40 mm da classe de potência: com 0,40 ela passava a 0,05 mm do `CHG_N` e levava a placa de 0 para 2 erros.

- **E uma via da mesma rede não fica a 0,2 mm de outra**: o `min_hole_to_hole` é 0,2 mm entre **bordas** de furo, o que com broca de 0,20 dá 0,40 entre centros. A conta antiga usava `VIA_D/2` e deixava passar o que o KiCad chama de `hole_near_hole`.

- **A célula saiu de baixo da placa e o pod ficou 30 % mais baixo** (2026-09-30, decisão do dono). Ela passa a ficar **ao lado** da placa: sai da pilha de altura e entra na de comprimento. O pod vai de **55,7 × 19,0 × 10,0** para **74,2 × 21,0 × 7,0**, e a pilha de altura deixa de somar a célula — fundo 1,0 + ar do verso 1,5 + placa 0,8 + teto 2,7 + tampa 1,0. A célula muda de forma com o que ela custa: embaixo tinha de ser comprida e estreita para caber entre os ressaltos (23 × 11 × 4,0 = 1.012 mm³ ≈ 78 mAh), ao lado quanto mais larga e grossa menos comprimento toma (**15 × 14 × 5,0 = 1.050 mm³ ≈ 81 mAh**), e os 5,0 mm de espessura são de graça porque a pilha da placa já reserva 5,0 no mesmo espaço. Efeito no que já era cobrado: `cola + pod` cai de 10,5 para **7,5 contra os 10,0** de folga de quadro, que era uma das duas falhas antigas.

- **Toda abertura do pod passa a ter vedação, e a regra enumera uma a uma** (`PD19`, 2026-09-30). O aparelho fica na face interna do braço, a centímetros do chão, e leva chuva, spray e mangueira: cada furo é um caminho de água até a placa, e não havia regra cobrando isso — o O-ring tinha a `PD13` e a janela do conector tinha a `PD3` e a `PD16`, e **o furo de luz, os dois parafusos e o rasgo dos fios da ponte não tinham dono**. Na primeira execução a regra reprovou **4 de 6 aberturas**. Entraram: resina transparente no furo de luz, tampão de resina de 0,8 mm sobre a cabeça de cada parafuso, e um **colar de 0,8 mm subindo 1,5** em volta do rasgo dos fios, que represa o envase (que senão escorreria por ali antes de curar) e alonga o caminho da água; por fora, quem fecha o resto é o adesivo que cola o pod ao braço. O colar é **desenhado e medido no desenho**, não só declarado numa constante.

- **`PD20`: a água que entra no poço do conector sai para fora, nunca para dentro.** O conector magnético é a única coisa exposta de propósito, então o poço enche; o que decide é para onde ele drena. A regra pegou de cara que a junta plana passava **0,05 mm** por cima do sulco do O-ring — as duas vedações uma sobre a outra —, porque o `J101` fica rente à borda da placa. A junta passou a ser grampeada na parede, com largura mínima cobrada (`JUNTA_MIN`).

- **`PD5`, `PD14` e `PD15` foram reescritas para a célula ao lado**, e as três acusaram o que deviam antes de serem trocadas: a célula fora da baia, o ressalto do parafuso esquerdo invadindo a bolsa (ele ficava na ponta esquerda, que virou a célula) e a célula sem nervura dos dois lados longos. Esta última era o berço medido contra `parede + ressalto`, e o ressalto é a borda onde a **placa** se apoia — a placa não chega mais àquela ponta do pod.

- **Fica em aberto uma coisa só, com o número dito**: o pod tem **21,0 mm de largura** e a face interna de um braço da classe tem 20,0, então ele sobra 0,5 mm de cada lado. A área de colagem cabe, o relevo livra a concordância e a folga do quadro passa — o que excede é só a silhueta. Fechar pede placa de 15 mm em vez de 16 (que custa roteamento) ou aceitar a sobra, e a `PD17` reprova com o número até a decisão.

- **Os valores eram grandes demais, e era isso que travava a placa** (2026-09-29, decisão do dono). Trilha e folga foram de 0,15 e 0,14 para **0,10 e 0,10**, a grade de 0,15 para **0,10** e a via de 0,45/0,25 para **0,40/0,20**, tudo dentro da capacidade normal de quatro camadas (a JLCPCB faz 0,0889 de trilha e de isolamento, furo de 0,20 e via de 0,40), com o DRC do projeto cobrando **0,09** para sobrar margem. Duas trilhas passaram a precisar de **0,20 mm** de eixo a eixo em vez de 0,29, ou seja 1,45 vez mais trilhas no mesmo canal. Efeito medido: o estágio sequencial subiu de **81 para 93 ligações**, as células disputadas da negociação cairam do patamar de **~650 para 30**, e os avisos de trilha e via soltas sumiram. A placa fica com **93 ligações, 651 segmentos, 217 vias, 0 erros de DRC e 21 itens desconectados**.

- **O que limita esta placa é a face de cima, e agora tem número** (2026-09-29). Medindo a grade antes de existir uma única trilha: **F.Cu tem 55,2 % de célula livre**, In2.Cu tem 87,1 % e B.Cu tem 81,6 %. Quase metade da face de cima já é ilha e folga. Depois do roteamento sobram 34,0 %, 46,8 % e 55,6 %. Por isso afinar a trilha ajuda (a trilha diminui) mas não fecha (a ilha não diminui), e por isso toda falha da fase sem partilha é `sem caminho até (x; y) na camada 0`: o gargalo é a **saída do pino**, não a área da placa, que está a 23 % de ocupação nas três camadas.

- **466 UUIDs repetidos faziam o relatório do DRC descrever o item errado** (2026-09-29). `footprints._pad()` derivava o UUID da ilha do número do pino e da posição **dentro** do footprint, que são os mesmos em toda instância do mesmo desenho: os dezessete resistores 0402 saíam com a mesma ilha "1". Eram 2.791 UUIDs escritos para 2.325 distintos, 43 desenhos repetidos até dezessete vezes. O KiCad guarda item por KIID, então a lista de desconectados vinha com pares entre **redes diferentes** (`Ilha 17 [UART_RX] de U201` contra `Ilha 1 [VBUS] de TP101`), o que não existe num ratsnest — e durante dias a informação sobre o que faltava fechar esteve errada. Corrigido em `make_pcb.uuids_unicos()`: cada UUID passa a levar a referência da peça.

- **A negociação não convergia porque a rodada incremental congela as redes inocentes** (2026-09-29). Com ripagem total a cada 6 rodadas, as células disputadas subiam dentro de cada ciclo e caíam a cada rodada total — 1.114, 1.217, 1.334, 1.344, 2.135, 3.441 e, na total seguinte, 798; num ciclo ruim chegaram a 6.456. E a economia que o incremental prometia não existia: as rodadas incrementais refaziam 37 a 42 das 43 redes. Com `RIPAGEM_TOTAL = 1` o patamar ficou estável.

- **A fase sem partilha destruía o trabalho da negociação** (2026-09-29). Ela fazia ripagem total e reconstruía a placa num passe guloso em que ninguém pode partilhar: as primeiras redes tomam os canais bons e as últimas ficam sem nada. Com a grade de 0,10 a negociação chegava a **30 células** disputadas e a primeira rodada sem partilha devolvia **26 ligações** sem caminho. Trinta células de conflito não podem custar vinte e seis ligações: agora, sem partilha, refaz-se só quem está no conflito, e as células caíram para 2.

- **O critério da melhor rodada pesa as duas coisas** (2026-09-29). Só células disputadas: o estágio escolheu 2 células e **56 ligações sem caminho**. Só ligações: escolheu 107 ligações com 240 pares perto demais e a placa saiu com 217 erros. A conta passou a ser `falhas + disputadas / 4`, e o 4 tem origem: um cruzamento marca umas quatro células e a limpeza o resolve tirando uma trilha, ou seja perdendo uma ligação.

- **A colocação ganhou um passe de melhoria por HPWL** (2026-09-29), que encurta **31,8 mm** de ligação e é o que fez a negociação fechar. Ele custa alguma coisa: solto, o desacoplamento é puxado para o centro das redes e a `AL1` piora de 7 de 17 capacitores fora do limite (média 3,06 mm) para 11 de 19 (3,85 mm). Preso de vez, o ganho cai para 3,5 mm; com coleira de 2 mm, para 5,8 mm; nos dois casos a negociação não fecha e a placa cai para o sequencial com 85 ligações. Fica solto, e a `AL1` continua o item grave que já era — ela não se resolve mexendo peça, e sim com mais área, que o dono não quer dar.

- **O que foi tentado e medido como PIOR, e por isso não entrou** (2026-09-29): reserva de fuga em volta de cada pino, com penalidade 60 e raio de 0,30 mm (3.913 células reservadas), levou a placa de 20 para **30** desconectados; costura de terra no passe de reparo pôs vias às cegas e deu **26 erros** de DRC, 14 deles de furo perto de furo, e medida pela grade cheia não achava lugar nenhum; o bloco do ADS1220 no verso tirou uma peça da placa, carregou `R201`, `R202` e `R203` de 14 a 25 mm e baixou o roteamento de 93 para 90; e o anel de fuga físico em volta do nPM1100 (1,4 e 1,9 mm) derrubou **seis peças** sem fechar nada.

- **`toco_limpo` não media vias**, enquanto a `conferir` do fim media: o toco passava aqui e o par aparecia lá como "1 par perto demais", e no KiCad como erro de isolamento. Duas medidas do mesmo fato têm de olhar as mesmas coisas. E a limpeza geométrica só tirava trilha encostada em **trilha**; o único erro que sobrou na placa da grade de 0,10 era trilha de `VBUS` a **0,065 mm** da ilha 2 do `C101`, que pede 0,090 — agora ela também sai.

- **Mais rodadas de negociação pioram** (2026-09-29). Com 30 rodadas o estágio fecha com **88 ligações, zero célula disputada, 21 itens desconectados e 0 erros de DRC**. Com 45 ele escolhe uma rodada de 107 ligações e 240 pares perto demais, que a limpeza não dá conta (217 erros); com 60, cai para 82 ligações, 28 desconectados e 2 erros. A fase sem partilha do fim é quem entrega a rodada limpa, e depois de certo ponto a pressão acumulada só espalha conflito. A constante fica em 30, com a medida ao lado.

- **O estágio de congestão negociada nunca tinha sido aceito, e era ele que faltava** (2026-09-29). O critério de aceitação exigia **zero célula disputada**, e nesta placa ele chega a zero só com 62 a 64 ligações, contra as 81 do sequencial — então era recusado em toda execução, depois de rodar 160 rodadas. Como agora existe a limpeza geométrica que tira a trilha e a via culpadas uma a uma, o resultado dele pode ser aceito e limpo depois. Com isso ele **fecha em 25 rodadas com 88 ligações e zero célula disputada**, e a placa vai de 551 para **1.383 segmentos**, de 81 para **88 ligações**, e de **30 para 21 itens desconectados, com 0 erros de DRC**. Das 44 que o roteador não fechou, **todas são de uma rede só** — a costura do plano de terra — contra 23 redes antes.

- **E o critério do melhor resultado tem de ser o mais LIMPO, não o mais completo** (2026-09-29). Trocado para preferir mais ligações, o estágio escolheu uma rodada com 107 ligações e **240 pares perto demais**; a limpeza tirou 40 trilhas e parou, e o DRC acusou **217 erros**. A rodada limpa entrega 88 ligações e **zero erro**. Medido nos dois sentidos antes de decidir.

- **O módulo de rádio estava na placa sem uma única ligação, e a placa foi publicada assim** (2026-09-28). As 36 ilhas do `U201` saíram do gerador **nomeadas pelo sinal** (`P1.04`, `VDD`, `GND`) em vez de numeradas, ao contrário de toda peça desta placa. A lista de nós pede `U201.P1.04`, o `parts.py` traduz esse nome para o número **18** pela tabela `PADS_HOLYIOT`, e o colocador procura a ilha `"18"` — que não existia. Resultado: **0 de 36 ilhas com rede**. O rádio não tinha alimentação, não tinha terra e não tinha sinal. **O DRC não viu nada**, porque ilha sem rede não tem com o que estar desconectada, e o `check_pcb` **viu** ("25 ligações da lista ficaram sem pad") mas esse número era tratado como informativo no `verificar_tudo.py`. Corrigido: ilhas numeradas 1 a 36, com o sinal em `pinfunction`, que é onde o KiCad o mostra e onde ele não entra na correspondência. Agora são **25 de 36 com rede** — as 25 que o esquemático pede, com os dois terras. No mesmo lugar, o desempate dos dois `GND` estava errado: `nomes.count(n)` era avaliado na lista que a própria volta já tinha alterado, então o primeiro virava `GND1` e o segundo ficava `GND`.

- **O nó de chaveamento saía estreito demais** (2026-09-28). `largura()` só consulta a tabela de correntes para as redes de `ALIMENTACAO`, e `BUCK_SW` não está nela — ele é um nó de chaveamento, não um trilho. Os 350 mA que a ficha do nPM1100 pede ao indutor eram roteados com **0,150 mm**, a largura de sinal, quando a curva da IPC-2221 pede **0,184** em camada interna. Passava por sorte, porque o nó só foi parar em camada externa e a `AL2` mede por segmento. Quem decide a largura é a **corrente**, não a lista em que a rede está.

- **As outras regras do roteador foram auditadas e estão certas** (2026-09-28), o que também é resultado: a folga de 0,14 mm é mais estrita que o `min_clearance` de 0,127 do próprio DRC; a folga de furo, o cobre à borda e o diâmetro de furo batem; e a largura de cada trilho sai da mesma tabela de correntes que a `AL2` cobra. E a folga de máscara de 0,35 mm foi **medida**, não argumentada: baixá-la para 0,25 ou 0,20 dá 3 a 4 erros de DRC e mais ligações abertas, então ela está protegendo e fica.

- **A trilha culpada também passa a sair.** A conferência geométrica já retirava a via de costura perto demais; um par de **trilhas** continuava sendo impresso com a linha "N pares perto demais" no relatório. Agora sai a do par que tem mais cobre — ela tem mais por onde voltar — e a ligação fica aberta, que é a escolha já registrada: um curto só aparece depois de fabricado, uma ligação faltando o `RT1` conta.

- **Um ponto de teste que não cabe tenta a outra face** em vez de sumir da placa. `TP104` e `TP301` ficaram de fora quando o desacoplamento do módulo passou a ser colocado de verdade, e o `check_pcb` os contou como ligação sem pad. Um ponto de teste é um pad para encostar a ponta de prova: não tem corpo nem altura, e o lado só existe para a face de trás ficar plana sob a célula.

- **Duas regras do projeto discordavam sobre o mesmo milímetro** (2026-09-28). A `ME2` da placa reprovava **toda** peça com corpo na face de trás, na premissa de que qualquer coisa ali se apoia na célula — e a `PD4` do pod media o ar sob **cada** uma delas e passava. A premissa da `ME2` deixou de valer quando a célula encolheu para 23 dos 47 mm da placa: passada ela o fundo do pod desce e há 1,0 mm, que é para isso que a zona `SOMBRA_VERSO_MAX_1-0MM` existe e por isso que [04](hardware_powermeter/04-placa.md) põe onze peças no verso de propósito. A `ME2` passa a conhecer os **dois** tetos da face de trás (0,0 mm sob a célula, 1,0 fora dela) e volta a cumprir. Duas regras do mesmo projeto discordando é pior que uma errada sozinha, porque as duas parecem medidas.

- **Rotear sobre uma placa que o KiCad salvou custa 4 ligações e 45 trilhas** (2026-09-28). Medido com a **mesma colocação e o mesmo código**, mudando só por onde o arquivo passou: direto do `make_pcb.py` dá 70 ligações na primeira passagem, 36 falhas, 440 segmentos e 31 não roteados; depois do `fill_zones.py` dá 64, 42, 395 e 35. Esvaziar as malhas **não** devolve o resultado bom — testado —, então não é o cobre despejado: é o arquivo inteiro, que o pcbnew reescreve à sua maneira. A ordem da cadeia sempre foi `make_pcb` → `route` → `fill_zones`, mas nada a **exigia**, e o resultado pior não avisava. Agora o `route.py` para e diz o que rodar. De quebra, ficou provado que o roteador é **determinístico**: duas execuções da mesma entrada dão o mesmo arquivo.

- **O passe de encosto final desenhava sem medir, e era ele que sujava a placa** (2026-09-28). O roteador terminava dizendo, com todas as letras, "conferência geométrica: 5 pares perto demais" — e gravava a placa assim mesmo. Os cinco viraram os quatro erros do DRC do KiCad, três deles o **mesmo defeito físico** (um toco de terra encostando na ilha `SHPACT` do `U101`, contado como curto, como isolamento e como ponte de máscara). Quem os desenhava era o passe que liga uma trilha que parou a um passo do próprio pad: ele já estreitava o pedaço e já conferia se a via cabia, mas **nunca media o segmento**. Um pad aberto por 0,15 mm virava um curto de 1,4 mm de trilha. Agora cada toco é medido contra todo o cobre e todas as ilhas das outras redes antes de ser aceito, e o que não passa não é desenhado: o pad fica aberto **dizendo por quê**. Resultado: **0 pares perto demais**.

- **O contador de ligações do roteador mentia** (2026-09-28). O passe incremental rota só as redes pendentes, e o `n_ok` dele conta só essas — mas virava o número do relatório da placa inteira. Uma placa com 395 segmentos foi relatada como "**1 ligações roteadas**". Passa a ser o total menos as que faltam.

- **O `AGENTS.md` era o do ciclocomputador, copiado e nunca adaptado** (2026-09-28). Ele mandava empurrar para `Guiimartinho/gnss-bike-computer` — **o repositório errado** —, dizia que `legacy/` é a especificação de comportamento (não existe `legacy/` aqui: este firmware é obra original, não um port) e apontava para um `tools/ui/` que não existe. Um agente que lesse só esse arquivo, que é exatamente para o que ele serve, faria as três coisas erradas. Refeito com o que é deste projeto, mais as armadilhas que custaram tempo hoje: o `bash` do PATH é o WSL, a cadeia de CAD tem ordem e intérprete certos, e uma regra de dry run que mede uma peça que saiu do projeto é pior que nenhuma.

- **O `verificar_tudo.py` chamava `bash` sem caminho** (2026-09-28). Num subprocesso do Windows isso abre o `C:\Windows\System32ash.exe`, o lançador do **WSL**, que este projeto proíbe — e ele existe nesta máquina, então o engano não dá erro: roda noutro sistema de arquivos. O script procura o bash do Git e **para dizendo isso** se não achar, em vez de rodar o errado.

- **A `US1` media um par diferencial que deixou de existir** (2026-09-28). O nRF54L15 não tem USB: os dois contatos do conector magnético que levavam `D+` e `D−` passaram a levar `UART_TX` e `UART_RX`, e a regra continuava medindo a largura de 90 Ω de `USB_DP`/`USB_DM`, redes que não estão mais na placa — a mesma doença da `ME7`. A 115200 baud não há par nem impedância a controlar; o que ainda importa é por onde as duas linhas passam, e o projeto já tem a geometria: `SEM_PLANO_BUCK_SW`, o retângulo dos pads do nó de chaveamento mais 0,6 mm, recortado de **todos** os planos porque é o ponto mais barulhento da placa. A regra mede se alguma das duas linhas o atravessa, em qualquer camada, e refaz o retângulo a partir dos pads **do arquivo da placa**, não da colocação que o gerador planejou. No `route.py` saíram os nomes mortos: medido antes de mexer, `PAR` não casava com rede nenhuma, `PRIMEIRO` valia só para `BUCK_SW` e `SO_FRENTE` não tinha rede roteável — o roteamento não muda, o código passa a dizer a verdade.

- **O verificador de pinos oferecia pinos que não existem nesta placa** (2026-09-28). Ele listava os GPIO livres do **SoC**, e o módulo traz 30 dos 34: `P0.05`, `P0.06` e `P1.00` não têm pad no HOLYIOT-26001-A. Quem fosse acrescentar uma função escolheria um pino sem cobre. Agora são duas listas separadas — nove livres **e presentes no módulo**, três livres só no SoC —, lidas de `PADS_HOLYIOT` em vez de digitadas de novo, e a linha dos pinos de clock passou a aplicar as mesmas exclusões: ela anunciava `P1.02`, que é pad de antena NFC.

- **O rip-up parcial do roteador divergia, e a correção é uma ripagem total periódica** (2026-09-28). Refazer só as redes que estão no caminho umas das outras é o que o PathFinder faz, e numa placa grande isso pega quase todo mundo; aqui o teste de partilha é geométrico, acha poucas redes, e o conjunto fica pequeno demais: as culpadas não têm para onde ir porque as inocentes estão congeladas, e o custo histórico não empurra quem nunca é refeito. Medido rodada a rodada: 420, 488, 528, 611, 972, 1292 e **1588 células disputadas na rodada 10**, com duas ligações perdendo o caminho — subindo, não acomodando. Com uma ripagem total a cada 6 rodadas as rodadas cheias caíram para 234, 199, 155 e **120**. A ripagem total também lava marca velha deixada em `uso`, que é como falha um `_desmarcar` que não seja o inverso exato do `_marcar`. Antes disso, duas correções sem as quais nada disso valeria: as redes culpadas passaram a ser anotadas **onde o conflito é achado** (a célula em `disputadas` é a do caminho, e o conflito está numa célula do disco de folga dele, então procurá-la depois em `uso` devolvia a própria rede e a outra nunca era refeita), e o melhor resultado passou a ser guardado como **cópia**, já que os caminhos agora são alterados no lugar.

- **A `ME7` media o módulo errado** (2026-09-28). Ela comparava o land pattern com um desenho de terceiros do ME54BS13 — peça que saiu do projeto —, e vinha falhando com uma mensagem sobre algo que não existe mais, o que é pior que não medir. Do HOLYIOT-26001-A não existe ficha em PDF, nem land pattern oficial, nem desenho de terceiros: comparar o footprint com as cotas que o geraram seria circular. A regra passa a medir o que ainda pega erro de gerador — uma ilha por pino da tabela do esquemático (36 para 36), o corpo do `F.Fab` igual ao de `footprints.CORPO`, nenhuma ilha saindo além do pé de solda de 0,5 mm, passo constante em cada fileira — e **diz em toda execução que isso não é conferência independente**. O primeiro desenho dela tirava o centro do corpo do envelope das ilhas, e isso estava errado: as ilhas não são simétricas em `y` (só a borda de baixo tem fileira), o corpo saía 1,9 mm fora do lugar e toda ilha de baixo parecia escapar da peça.

- **A célula de 2,5 mm não existia** (2026-09-28). O pod era desenhado em volta de "uma LiPo de 100 mAh com 2,5 mm de espessura"; em 23 × 11 × 2,5 mm uma LiPo de bolsa vale cerca de **49 mAh**, que a 1,5 mA dão 32 h contra as 50 h do requisito. A conta nunca tinha sido feita. A célula que cabe e atende é de classe **`401123`** (4,0 × 11 × 23 mm, ≥ 78 mAh, dois fios, proteção integrada), e ela custa 1,5 mm de altura: o pod vai de 8,5 para **10,0 mm**, encostado no alvo. Nenhuma loja foi alcançada — DigiKey, Mouser, AliExpress e seis brasileiras recusaram a conexão desta máquina —, então o envelope e a capacidade são **requisito de compra**, não peça escolhida.

- **O nRF54L15 não tem USB, e isso custa exatamente um GPIO** (2026-09-28). Conferido no NCS instalado, não de memória: `usbhs` aparece seis vezes em `nrf54lm20_a_b.dtsi` e **zero** em `nrf54l_05_10_15.dtsi`. O módulo por isso não tem pino `VBUS` — o pad 9 é o `P2.00`, um GPIO comum que os 5 V do cabo destruiriam. Os dois contatos do conector magnético que levavam `D+` e `D−` passam a levar `TX` e `RX`: a serial dos comandos e a recuperação do MCUboot. Eles **continuam chegando ao nPM1100**, que lê essas linhas sozinho para escolher entre 500 mA e 100. E como nada mais avisa que o cabo entrou (o `usb_svc.c` registra que o nPM1100 não tem pino para isso), um divisor de 1 M / 470 k leva 5,0 V a 1,60 e entra num GPIO, lido nas duas bordas **e na partida**, porque o cabo pode já estar lá quando o pod liga.

- **O mapa de pinos não rodava no SoC novo, e o verificador conferia contra o chip errado** (2026-09-28). O mapa usava `i2c23` em `P1.29` e `uart20` em `P1.31`, e no nRF54L15 a porta `P1` tem 16 pinos e o bloco 23 não existe. Refeito com os pinos que a **própria Nordic** usa no NCS para cada periférico — `spi00` em P2.01/02/04, `i2c22` em P1.11/P1.12, `uart20` em P1.04/P1.05 — porque o `SCL` de um TWIM e o `SCK` de um SPIM precisam de pino com clock. O `board_check.py` reprovou o `P1.11`, que é justamente o que a Nordic usa: ele carregava a tabela 79 da ficha do **nRF54LM20A**, de outro chip, e as portas de 10/32/11/13 pinos em vez de 7/16/11. Agora a lista de pinos de clock cita o arquivo do NCS de onde cada um saiu, e diz "não há evidência" em vez de "não é pino de clock", que é o que ela pode afirmar.

- **O bootloader não cabe em 64 KB nem precisa de 96** (2026-09-28). Sobre UART o MCUboot mede 46.996 B no pod e 53.324 no DK, contra os 89.204 que a recuperação por USB CDC pedia. Mas o padrão do fabricante, 64 KB, também não serve: o **FPROTECT cobre no máximo 62 KB** nesta série e o MCUboot afirma isso em tempo de compilação. Desligar o FPROTECT deixaria o bootloader gravável pela aplicação que ele carrega, que é a única coisa que ele existe para impedir, então ele fica com **60 KB** — o maior múltiplo de 4 KB abaixo do limite. E o console **do bootloader** fica desligado na imagem dele, porque o `serial_adapter.c` recusa compilar com ele ligado: a recuperação toma a UART e um console nos mesmos pinos corromperia os quadros SMP.

- **Um desencontro silencioso entre as partições** (2026-09-28). O `sysbuild/mcuboot.overlay` vale para **todos** os alvos, então quando ele foi para slots de 664 KB o overlay do DK continuou dizendo 904 — um bootloader que grava a imagem onde a aplicação não a espera — e as duas imagens ligaram sem uma palavra. Os três devicetrees carregam a mesma tabela agora.

- **Nenhum dos dois estágios do roteador sabia dizer se tinha ligado** (2026-09-28). O estágio de congestão negociada encerrou anunciando "96 ligações, 0 células disputadas" com **onze pads sem cobre nenhum**, entre eles os três terminais do `USB_DM`, que ficou em três pedaços soltos de 0,9 mm. Foram três defeitos distintos, cada um medido: o critério de aceitação comparava *número de ligações* (`n_ok_n > n_ok`) em vez de pads abertos; ao aceitar o resultado do negociado, o cobre sequencial das redes que ele **não** rodou era descartado (16 → 12 abertos ao herdar); e o cobre herdado não era dado ao negociado como obstáculo, então ele planejava sobre placa vazia (182 violações, que caíram para 25 ao passar `pre_seg`/`pre_via`). Quem julga passa a ser o DRC do KiCad: o `reparar.py` lê `_drc_all.json`, parte sempre de um **pad** — começar por uma trilha faz o A* achar alvo na própria trilha e emitir um toco que liga ela nela mesma, e foi assim que cinco ligações foram dadas como fechadas sem fechar — e recusa desenhar o que não encosta.

- **Uma via não é de graça, e a que eu punha sem conferir custou quatro erros** (2026-09-28). A via atravessa todas as camadas, logo tem de se afastar de todas as redes em todas elas. Posta às cegas para encostar uma trilha num pad, uma via de `GND` caiu sobre o pad `3V0_MOD` do `C201`: dois curtos, um isolamento de furo e uma ponte de máscara de solda — por uma ligação que nem fechou. `route.via_cabe_aqui` confere antes; sem lugar, o pad fica aberto e diz isso.

- **`SO_FRENTE` era lei e devia ser preferência** (2026-09-28). O par USB foi calculado como microstrip de 90 Ω em `F.Cu` sobre o plano a 0,10 mm, e em `In2.Cu` não é 90 Ω de nada — mas com a restrição como lei o `USB_DM` simplesmente não fecha: são 16,7 mm de `J101` a `U101` e 8,3 mm até `U201` por uma face de cima cheia. O aparelho fala USB **full speed**, 12 Mbit/s, onde o próprio `make_pro.py` já registrava que a folga maior do outro projeto não comprou nada. A busca tenta a frente nas duas folgas e só troca de camada se não houver caminho, avisando quando trocou.

- **A designação de compra está fechada para os braços do dono** (2026-09-28): ele começa por Shimano 105 e Ultegra, os dois de liga de alumínio, então o código de autocompensação é o **13** e a peça é **`N2K-13-S5229A-50C/DG/E3`**. Duas armadilhas do databook ficaram registradas: sem o código escrito no pedido o fabricante **embarca o 06**, que é o de aço, e o fator de grade da liga K é 2,1 e não 2,0, o que deixa as contas deste projeto conservadoras em 5 %. E o braço Shimano é **oco**: com parede de 3 mm o momento de inércia cai de 9.333 para 7.504 mm⁴ e a deformação sobe de 459 para **571 µε**, 24 % mais, o que dá 2,28 mV com a ponte de Poisson do S5229. Para aço muda só o código, para `06`; carbono é estudo à parte, porque o S-T-C é a dilatação do material e a de carbono-epóxi é perto de zero na direção das fibras.

- **A ponte completa de 5 kΩ numa peça só existe, e tem nome** (2026-09-28). O databook de classe transdutor do fabricante (2622-EN, 116 páginas) diz que os padrões de alta resistência vêm também em configuração de ponte completa, com até 10 kΩ, e lista cinco candidatos. O escolhido é o **S5229**, designação `N2K-13-S5229A-50C/DG/E3`: 5000 Ω ±5 %, matriz de **4,0 × 3,7 mm**, ponte já balanceada a ±0,5 mV/V de fábrica, liga Karma sobre poliimida, ilhas douradas, `13` de autocompensação para alumínio. Uma colagem em vez de quatro, o consumo fica em 1,5 mA e o pod em 8,5 mm. O desenho mostra ponte de Poisson, duas grades longitudinais e duas transversais, que num campo de flexão dá cerca de dois terços de uma ponte de flexão pura e ainda assim seis vezes o cisalhamento. Alternativa em 1000 Ω específica para viga em flexão: **S5067**.

- **O padrão de extensômetro especificado está errado para um braço de pedivela** (2026-09-28). A lista pede padrão de cisalhamento a 45°, que é padrão de torquímetro de eixo; o braço é viga em balanço. Numa seção de 20 × 14 mm de alumínio, com 500 N tangenciais e a grade a 60 mm do pedal, a grade a 45° no meio da face lê 52 µε e a grade axial junto da borda lê 459 µε: **8,9 vezes mais**. E são os 459 µε que correspondem aos "1 a 3 mV" que `docs/06` já declarava, ou seja, os números do documento sempre descreveram flexão. O cisalhamento ainda é frágil: só é máximo na linha neutra, e a 2 mm dela entra a flexão, nove vezes maior. Recomendação registrada em `docs/06`: ponte cheia de flexão, quatro grades axiais, duas por borda, que também cancela flexão lateral, força axial e temperatura. A escolha puxa a resistência junto, porque padrão de ponte cheia num filme só existe sobretudo em 350 e 1000 Ω, e 1000 Ω traz o consumo de volta a 3 mA.

- **O envelope da classe, por fotogrametria, porque ninguém o publica** (2026-09-27). A foto de imprensa do fabricante traz o módulo colado num braço Shimano FC-M8100 marcado 170, e o centro do furo do eixo ao centro do furo do pedal são exatamente 170 mm: 0,1319 mm por pixel. A escala foi conferida por um segundo caminho, os dois contatos de carga do módulo, que dão 2,6 mm entre centros, o passo padrão de 2,5 mm de pino pogo, com cabeças de 1,3 a 1,6 mm. Resultado: **37 a 39 mm de comprimento**, 18 a 22 de largura e 9 a 13 de altura, esta última fraca porque nenhuma foto tem perfil. O alvo do projeto passa de 60 para **38 mm de comprimento**: o que se perseguia já era quase o dobro do que a classe faz.

### Decidido

- **O módulo de rádio passa a ser o HOLYIOT-26001-A, com o nRF54L15** (dono, 2026-09-28). O motivo é um só e foi medido: o módulo era **26 % da área da placa numa peça só**, mais que as 37 peças pequenas somadas, e é a única alavanca de tamanho — 0402 em tudo e a quarta camada de cobre foram medidos antes e a placa já tinha os dois. Ele é 10,0 × 12,5 contra 12,0 × 16,5, e a largura é o ganho maior, porque é o módulo que põe o piso da largura da placa: 16 → 14 mm na placa e 19,4 → 19,0 no pod, que absorve junto o que a vedação nova custa. Custa o **USB**, que este SoC não tem, e 188 KB de RAM em vez de 511. Detalhes em [`hardware_powermeter/09`](hardware_powermeter/09-modulo-de-radio.md).
- **A case passa a ser vedada, aparafusada e drenada** (dono, 2026-09-28): anel O de 0,80 mm num sulco de 1,05 × 0,58 cortado na face da parede (27,5 % de compressão), dois parafusos M1,6, berço de nervuras para a célula, placa prensada entre os pilares e dedos que descem da tampa, e um lábio em volta da janela do conector com um corte de 1,2 mm que serve de dreno. Cada uma tem uma regra que a mede, e o dry run do pod foi de 12 para **16 regras, todas cumpridas**.
- **A célula estreita de 13 para 11 mm** (2026-09-28), porque a placa foi a 14: entre os ressaltos sobram 13,8 mm e uma nervura de berço pede 1,05 deles. São 633 mm³ contra 748.

- **Extensômetros de 5 kΩ** no lugar de 1 kΩ (dono, 2026-09-27): a ponte cai de 3,0 para 0,6 mA e o total pedalando de 3,9 para 1,5 mA, o que faz as 50 h fecharem com uma célula de 100 mAh em vez de não fecharem com 150. O ruído térmico de 5 kΩ em 10 Hz é 0,03 µV, contra 0,26 µV do conversor, então não se paga em resolução. Falta confirmar que existe padrão de cisalhamento a 45° nessa resistência; se não existir, a saída é o modo duty-cycle do conversor, não voltar a 1 kΩ.
- **O pod tem de ficar perto de 60 × 20 × 8,5 mm nas três medidas** (dono, 2026-09-27). O primeiro desenho deu 65,4 × 19,4 × 10,5. A altura fecha exatamente com a célula mais fina que os 5 kΩ permitem (4,0 para 2,5 mm) e o teto de volta a 2,7 mm, com a célula soldada por fio em vez de conector. O comprimento pede a placa em cerca de 55 mm, com passivos baixos na face de trás **fora da sombra da célula**, que cobre 23 a 25 mm dos 60: os outros 35 ficam sobre o fundo do pod e um passivo 0402 pede 0,6 mm de vão contra os 2,5 da célula, então não custa altura.
- **Licença CC BY-NC 4.0** (`LICENSE`), a mesma do GNSS Bike Computer. Não é licença aprovada pela Open Source Initiative, que não admite restrição de uso, e foi escolhida por isso. O firmware deste projeto é obra original, não um port, e a licença diz isso.

### Corrigido

- **O desacoplamento de dois chips do verso ficava na frente, a 11 e 12,6 mm do pino** (2026-09-28). O `U302` (chave de carga) e o `U402` (TMP117) foram para a face de trás porque não cabiam na frente, mas `C307`, `C308` e `C403` ficaram para trás — do outro lado da placa, num anel já ocupado por `C401`, `C402`, `U401`, `C304`, `C306` e quatro pontos de teste. A ficha do TMP117 pede 0,1 µF **junto do pino**. Os três passam para o verso, na mesma face dos chips que servem, e o colocador deixa de reclamar.

- **Três regras dos dry runs não mediam o que diziam medir** (2026-09-28). A `PD4` reprovava **qualquer** corpo na face de trás, mas a célula cobre 23 dos 48 mm da placa e depois dela o fundo do pod desce: ela passa a medir o ar sob cada peça, contra a célula, a nervura, os pilares ou o fundo. A nervura estava saindo com **0,0 mm** porque o conector da ponte cai 0,2 mm depois da célula e a clipava a zero — agora ela vai para depois do rasgo, que segura o mesmo vão. E os dois pilares pousavam num pad passante do `J102`: eles deslizam em y até sair de cima de qualquer pad da face de trás.

- A lista de componentes dizia que o `bosch,bma4xx` da árvore opera o BMA400; ele reconhece o chip ID `0x90` com um aviso e usa o mapa de registradores do BMA422, que é outro. A coluna passa a dizer "Não: driver próprio", como já diziam `docs/04` e o `CLAUDE.md` (2026-09-27).

- **Os eixos do acelerômetro estavam invertidos no firmware, e ninguém tinha como saber.** A orientação era suposição (`PM_IMU_AXIS_RADIAL` em X, `_TANGENTIAL` em Y) e não estava em documento nenhum, então nada podia confirmar e nada falharia se a placa saísse de outro jeito. `docs/02` passou a trazer o requisito eixo a eixo com a convenção da seção 8.2 da ficha; a medida contra o canto do pino 1 do footprint e a rotação do `U401` mostrou o contrário do suposto, e os três símbolos passam a radial = Y, tangencial = X e sinal do radial −1. A regra `IM1` do dry run da placa reprova enquanto os dois lados discordarem. Invertidos, o termo centrípeto entraria na cadência e a potência sairia errada sem nenhum sinal de erro (2026-09-27).
- **A atualização por BLE não funcionaria e a calibração era escrita por qualquer um.** O serviço SMP herdava o padrão do Zephyr, que com o gerenciador de segurança ligado exige emparelhamento **autenticado**: um pod sem tela nem teclado emparelha por Just Works e nunca chega a esse nível, então a característica seria impossível de escrever. E as características de comando e de configuração aceitavam escrita sem cifra nenhuma, de qualquer rádio ao alcance. As três passam a exigir ligação cifrada, que é o nível que o aparelho alcança (2026-09-27).
- `docs/05` descrevia o serviço de configuração sem dar os UUID, que existiam só no código: sem eles ninguém escreve o app. Os cinco estão na tabela, com a regra de formação e como o aparelho é achado (2026-09-27).
- A linha do SWD na tabela de pinos de `docs/02` dizia que o reset vai ao conector magnético junto com `SWDIO` e `SWDCLK`; o conector tem seis contatos e não leva o reset, que existe só no Tag-Connect, como o esquemático sempre mostrou (2026-09-27).
- Os `.bat` da raiz vinham do ciclocomputador com o nRF52840 DK como alvo padrão, que este projeto não tem, e sem o `tools/fw/ncs_env.bat` que eles chamam: passam ao nRF54LM20 DK, como o `fw.sh`, com o ambiente do `cmd` copiado; e as skills de build, testes, threads, documentação e commit descrevem este firmware, os seus três alvos e a regra dos 95 % de cobertura, em vez do port do stravaV10 (2026-09-27).
- O orçamento de consumo de `docs/02` contava a ponte ligada 15 % do tempo; o ADS1220 integra a conversão inteira, e a ponte de 1 kΩ fica ligada enquanto se mede: 3,9 mA pedalando, abaixo das 50 h do requisito, com as três saídas para o dono decidir (2026-09-27).

### Adicionado

- Hardware de ponta a ponta, gerado por script: o esquemático em 4 folhas (57 peças, 45 nós, ERC sem erro, netlist conferido pino a pino), a placa de 60 × 16 mm em 4 camadas (57 peças, 546 segmentos, 179 vias, **DRC com 0 erros**, 77 das 110 ligações fechadas) e o pod de 65,4 × 19,4 × 10,5 mm com 17,0 g estimados. PDF do esquemático, PDF das camadas, desenho de montagem, vistas 3D da placa e do pod, e STL da concha e da tampa (2026-09-27).
- Cadeia de CAD portada do ciclocomputador para `hardware_powermeter/cad/` e `pod/`, com as tabelas desta placa e três correções medidas no roteador (ordem das ligações a partir do pino mais próximo; pescoço dentro do campo de pads; isolação reservada pela trilha mais larga, que trocou 17 ligações por zero erro de DRC) (2026-09-27).
- Regra `ME7`: o land pattern do módulo de rádio comparado pad a pad com um desenho independente do mesmo módulo. **80 pads, desvio máximo 0,000 mm** — a primeira conferência independente de um footprint que a ficha não publica (2026-09-27).
- Regra `IM1`: os eixos do acelerômetro medidos na placa contra a seção 8.2 da ficha. O resultado **reprova**: o `X` do sensor fica tangencial e o `Y` radial, ao contrário do que `PM_IMU_AXIS_RADIAL` e `_TANGENTIAL` supõem ([`hardware_powermeter/04`](hardware_powermeter/04-placa.md#a-orientação-do-acelerômetro)) (2026-09-27).
- Regras `TX1` e `TX2` (`cad/sch_legivel.py`): a legibilidade do esquemático medida no PDF exportado, palavra por palavra. Achou 81 pares de texto sobrepostos; as correções do gerador (altura real do glifo, 2,43 mm e não 1,27; mais espaço entre peças vizinhas) levaram a 38 (2026-09-27).
- Doze regras de dry run do pod (`PD1` a `PD12`), que mudaram quatro medidas do desenho no mesmo dia: o teto subiu para 3,2 mm porque quem o fixa é o conector da célula, a célula encolheu para 23 mm por causa do rasgo dos fios da ponte, a aba da tampa afinou e o rasgo estreitou (2026-09-27).
- Documentos de hardware 02 a 08: esquemático, lista de nós, placa, materiais, conectores e pontos de teste, pod e o relatório de dry run (2026-09-27).

- O `tools/fw/board_check.py` passa a conferir também o **esquemático**: todo pino do módulo na tabela de `docs/02` está numa rede de `hardware_powermeter/cad/nets.py`, e vice-versa, e nenhum pino do módulo aparece em duas redes. É o que impede a placa de ser fabricada com uma pinagem e o firmware compilado com outra, que só a bancada acusaria. Os 19 pinos batem nos três lados: silício, documento e esquemático (2026-09-27).

- Firmware embarcado inteiro: base (`main`, zbus, watchdog, `pm_store`, `app_cmd`), drivers próprios do ADS1220 e do BMA400 em `modules/pm_drivers`, os seis serviços, o CPS e o serviço de configuração por BLE, a atualização por mcumgr, a porta serial USB, o ANT+ BPWR com `ANT=1` e o overlay do nRF54LM20 DK; compila com zero avisos, pilhas medidas com `CONFIG_STACK_USAGE`, nunca executado (2026-09-27).
- A recuperação serial do MCUboot pelo USB CDC ACM do conector magnético, sem botão (espera de 1 s a cada partida), com o MCUboot em 96 KB e os slots em 904 KB; e o `$SLEEP` como evento da máquina do sistema, testado no PC (2026-09-27).
- A placa própria do pod (`pmboard/nrf54lm20a/cpuapp`, `zephyr_app/boards/pm/pmboard`) com os pinos de `docs/02`, e `tools/fw/board_check.py`, que confere o devicetree contra o silício e contra a tabela de `docs/02` (2026-09-27).
- O comando `$SHIP` (ship mode do nPM1100) e a distinção dele do `$SLEEP` (System OFF com despertar pelo acelerômetro) (2026-09-27).
- Modelo de protocolo e de sistema em C puro (`cps_encode`, `pm_settings`, `pm_cmd`, `health`, `pm_fsm`, `pm_wire`) com 67 casos de teste de host, 100 % das linhas e cinco mutações mortas; o bloco de configuração passa a ser binário versionado com CRC-16 em vez de CBOR, e a máquina do sistema mora no modelo em vez do SMF; `docs/07-status.md` vira a matriz de estado do projeto (2026-09-27).
- Modelo de medição em C puro (`bridge_calc`, `crank_angle`, `rev_power`, `calib`) com 66 casos de teste de host, cobertura por linha medida pelo gcov (`tools/fw/coverage.py`, 100 % nos quatro) e sete mutações mortas (2026-09-27).
- Estrutura do repositório, espelhando o ciclocomputador, e a lista fechada de componentes com o número do datasheet de cada peça (2026-09-27).

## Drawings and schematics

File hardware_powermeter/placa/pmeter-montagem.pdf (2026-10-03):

# Montagem - frente

# Bike Power Meter - placa 50 x 16 mm - NADA FABRICADO NEM MEDIDO

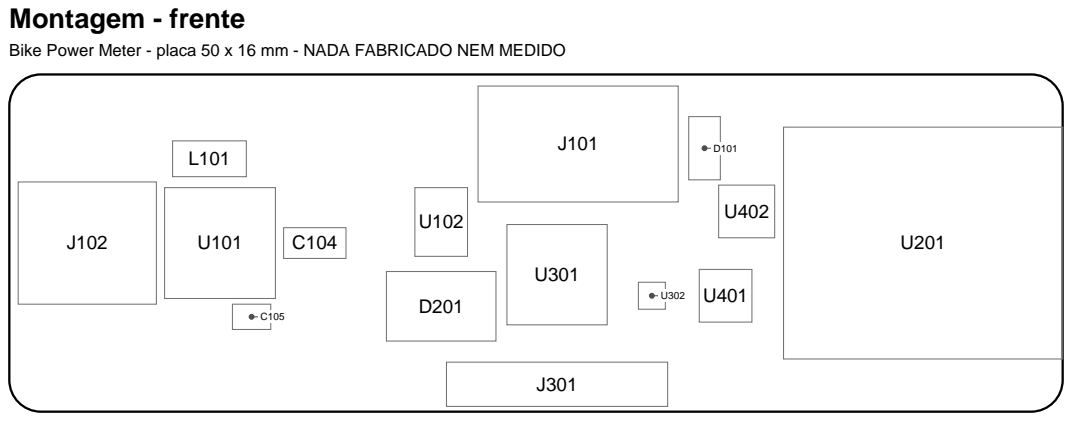
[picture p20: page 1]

# Montagem - verso

# Bike Power Meter - placa 50 x 16 mm - NADA FABRICADO NEM MEDIDO

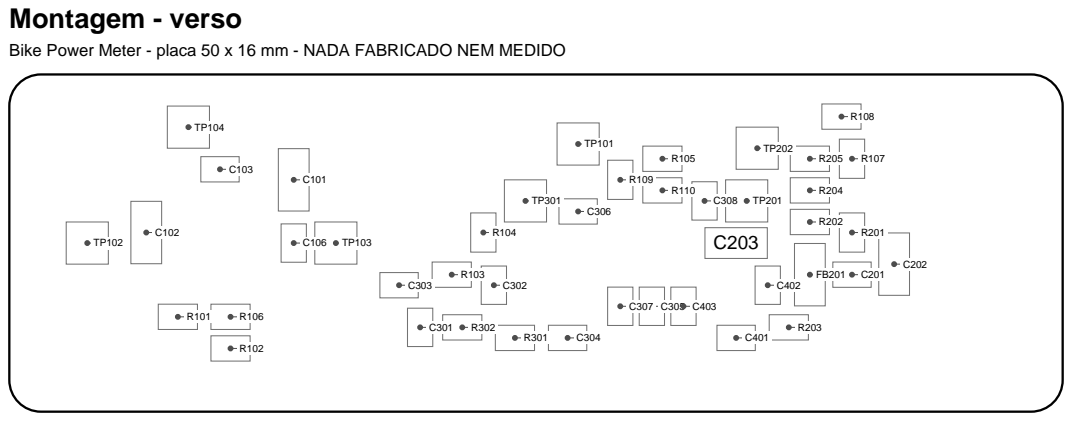
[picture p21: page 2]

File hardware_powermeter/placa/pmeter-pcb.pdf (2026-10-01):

## 1 - F.Cu: frente

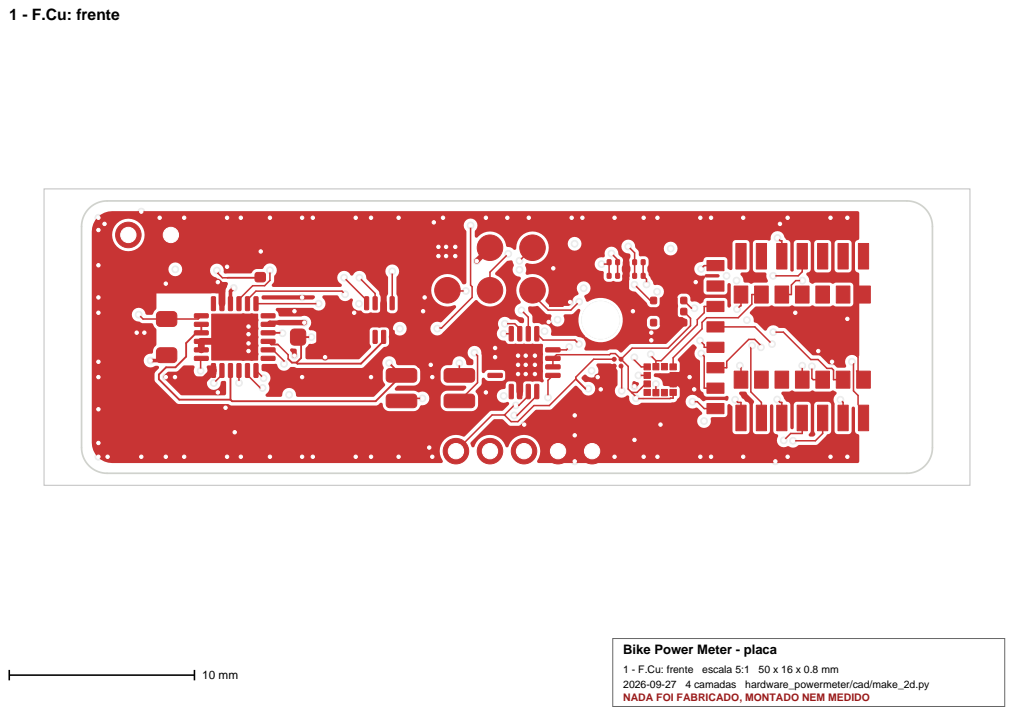
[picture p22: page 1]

Bike Power Meter - placa
1 - F.Cu: frente escala 5:1 50 x 16 x 0.8 mm
2026-09-27 4 camadas hardware_powermeter/cad/make_2d.py
NADA FOI FABRICADO, MONTADO NEM MEDIDO

## 2 - In1.Cu: plano de terra

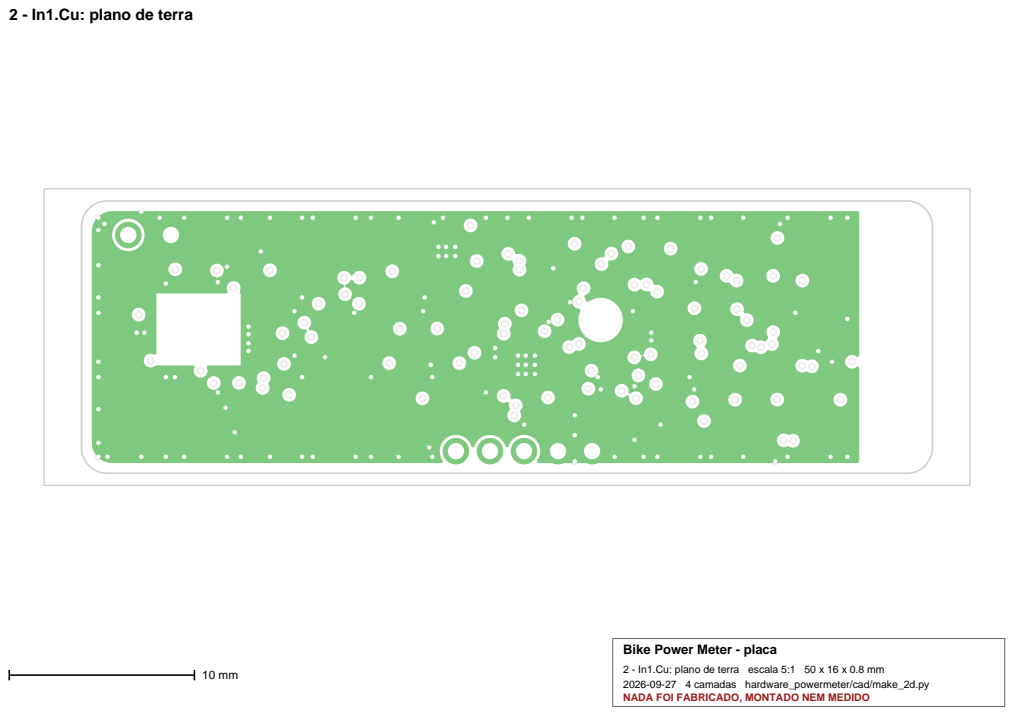
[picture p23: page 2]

Bike Power Meter - placa
2 - In1.Cu: plano de terra escala 5:1 50 x 16 x 0.8 mm
2026-09-27 4 camadas hardware_powermeter/cad/make_2d.py
NADA FOI FABRICADO, MONTADO NEM MEDIDO

## 3 - In2.Cu: roteamento interno

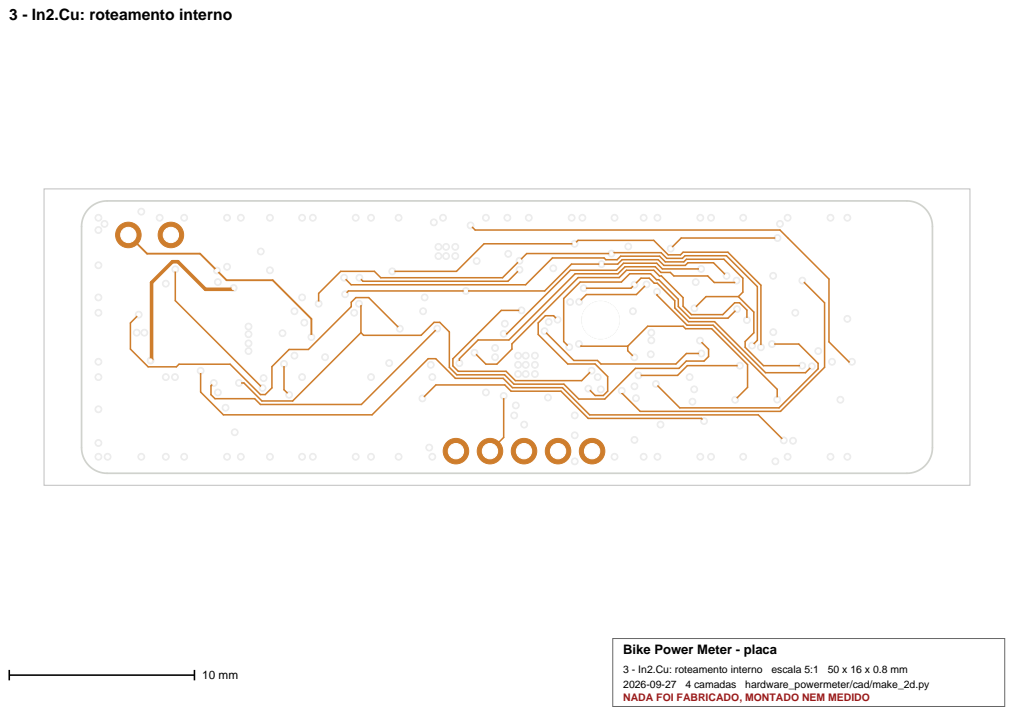
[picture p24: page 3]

Bike Power Meter - placa
3 - In2.Cu: roteamento interno escala 5:1 50 x 16 x 0.8 mm
2026-09-27 4 camadas hardware_powermeter/cad/make_2d.py
NADA FOI FABRICADO, MONTADO NEM MEDIDO

## 4 - B.Cu: verso

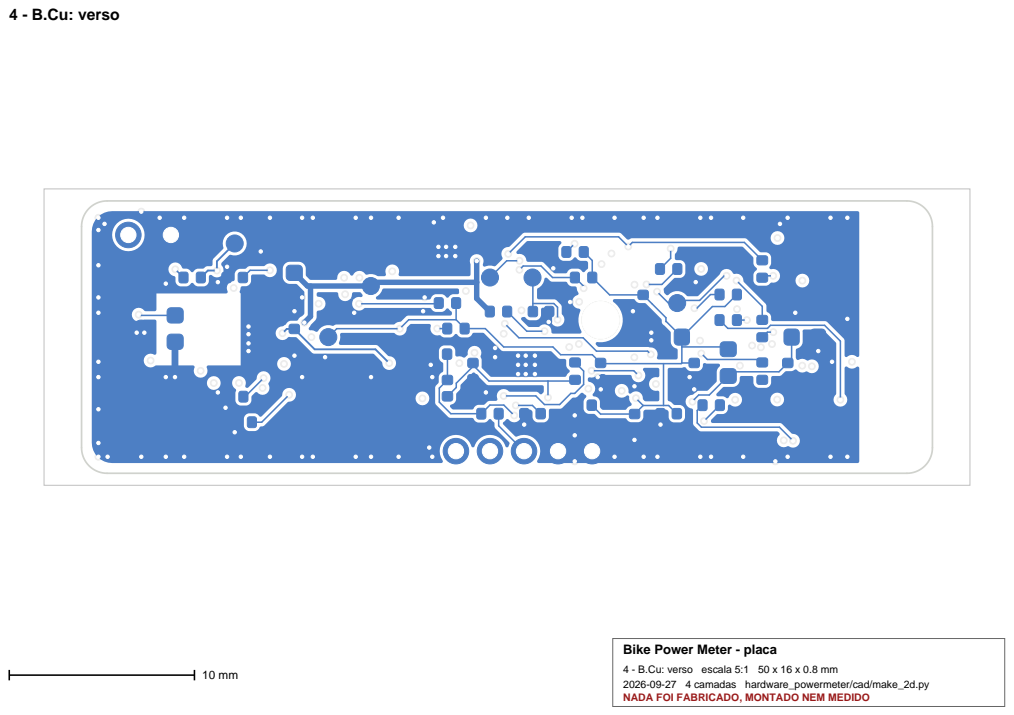
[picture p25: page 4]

Bike Power Meter - placa
4 - B.Cu: verso escala 5:1 50 x 16 x 0.8 mm
2026-09-27 4 camadas hardware_powermeter/cad/make_2d.py
NADA FOI FABRICADO, MONTADO NEM MEDIDO

## 5 - montagem da frente: serigrafia

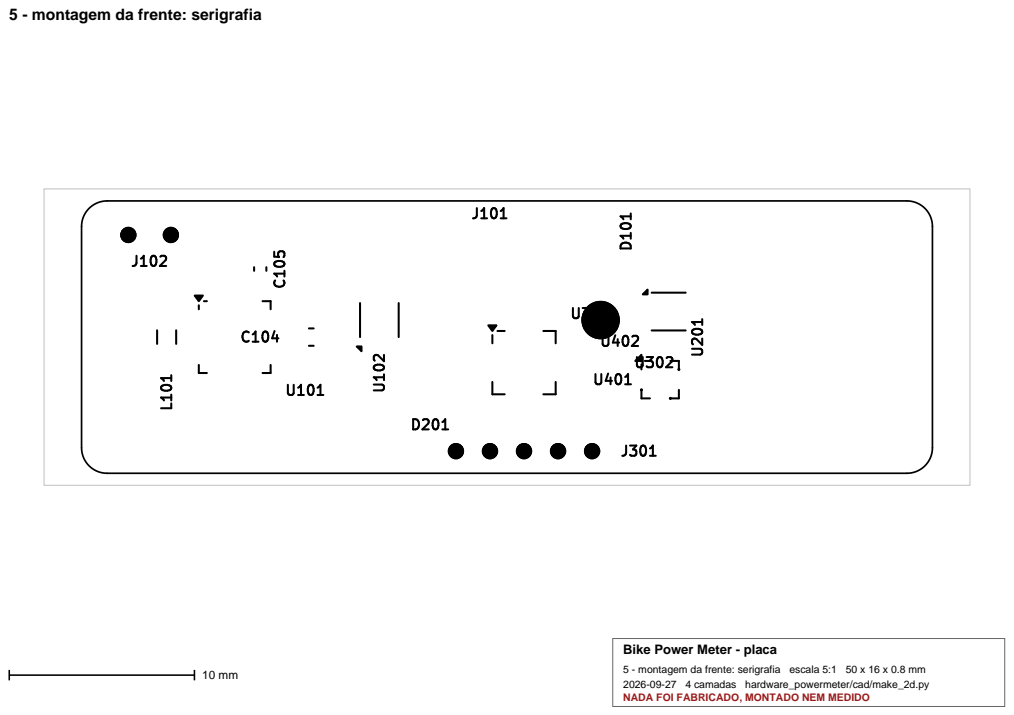
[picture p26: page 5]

Bike Power Meter - placa
5 - montagem da frente: serigrafia escala 5:1 50 x 16 x 0.8 mm
2026-09-27 4 camadas hardware_powermeter/cad/make_2d.py
NADA FOI FABRICADO, MONTADO NEM MEDIDO

## 6 - montagem do verso: serigrafia

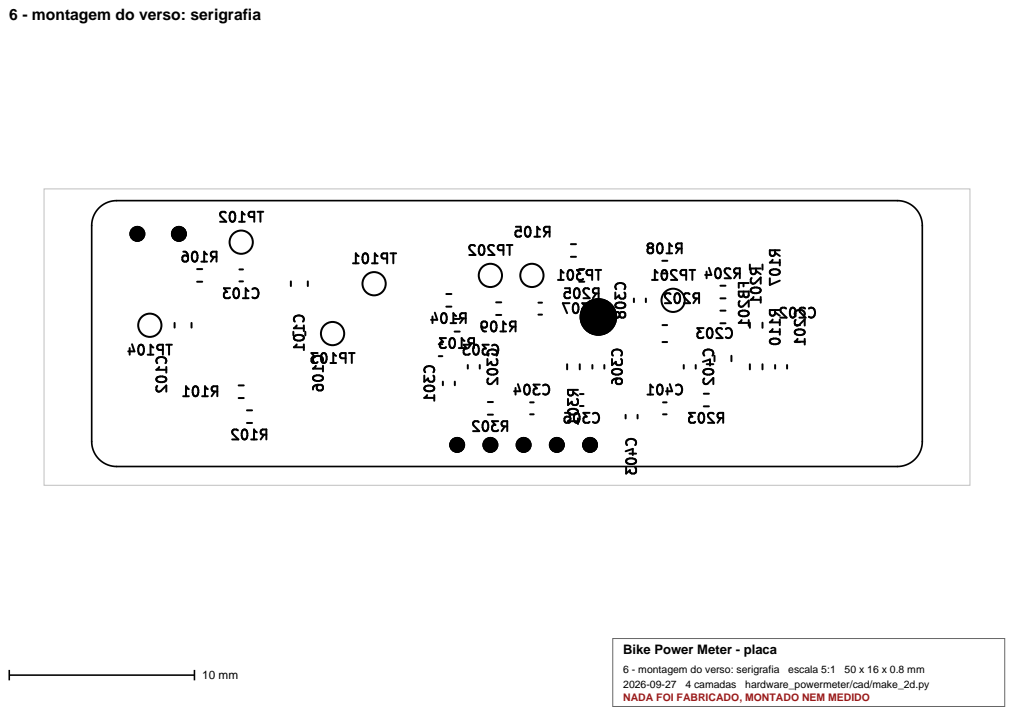
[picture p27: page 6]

Bike Power Meter - placa
6 - montagem do verso: serigrafia escala 5:1 50 x 16 x 0.8 mm
2026-09-27 4 camadas hardware_powermeter/cad/make_2d.py
NADA FOI FABRICADO, MONTADO NEM MEDIDO

## 7 - as quatro camadas juntas

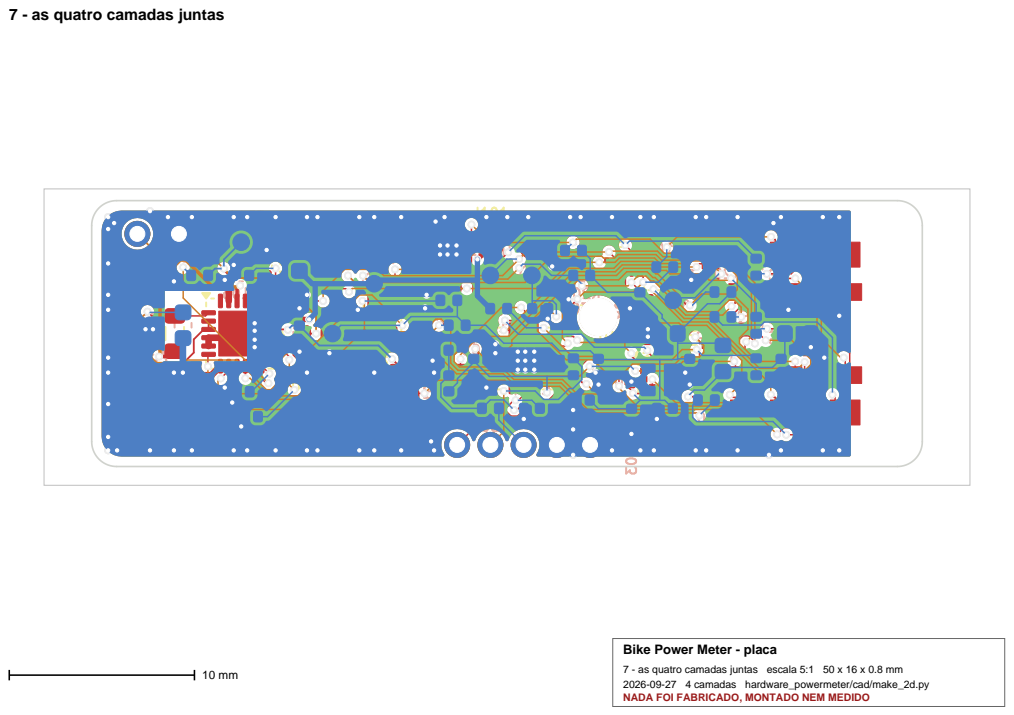
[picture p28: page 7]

Bike Power Meter - placa
7 - as quatro camadas juntas escala 5:1 50 x 16 x 0.8 mm
2026-09-27 4 camadas hardware_powermeter/cad/make_2d.py
NADA FOI FABRICADO, MONTADO NEM MEDIDO

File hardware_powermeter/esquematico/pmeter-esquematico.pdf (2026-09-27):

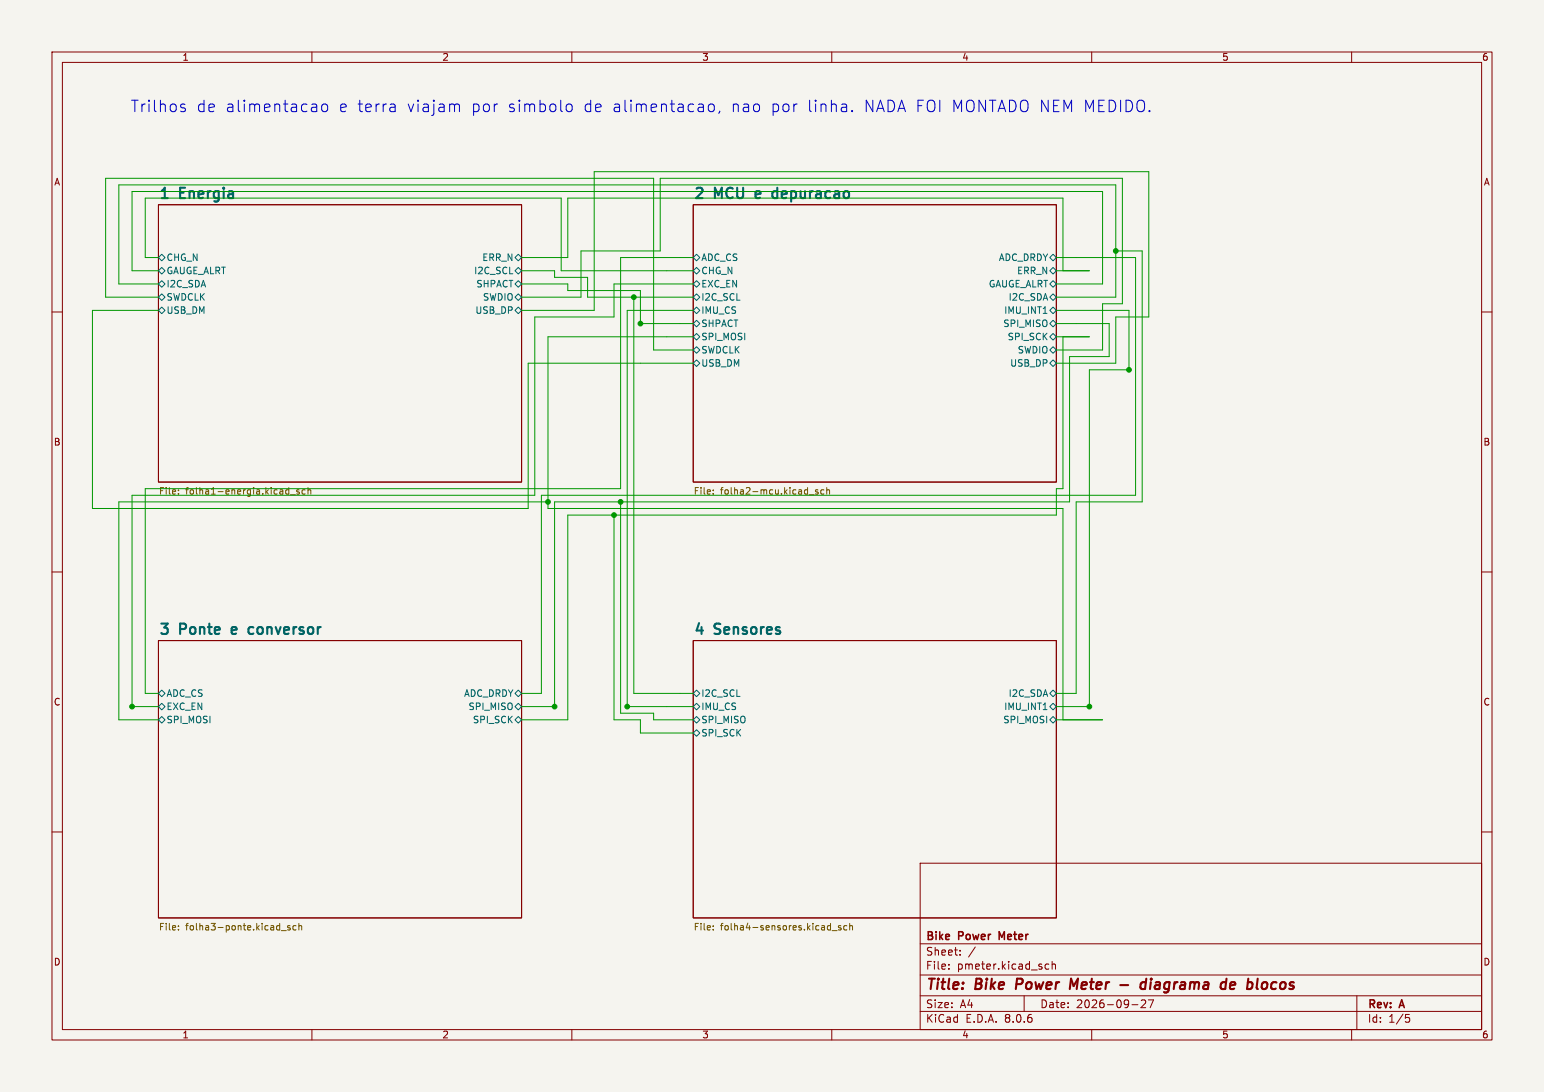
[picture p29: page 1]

Id: 1/5 Title: Bike Power Meter - diagrama de blocos

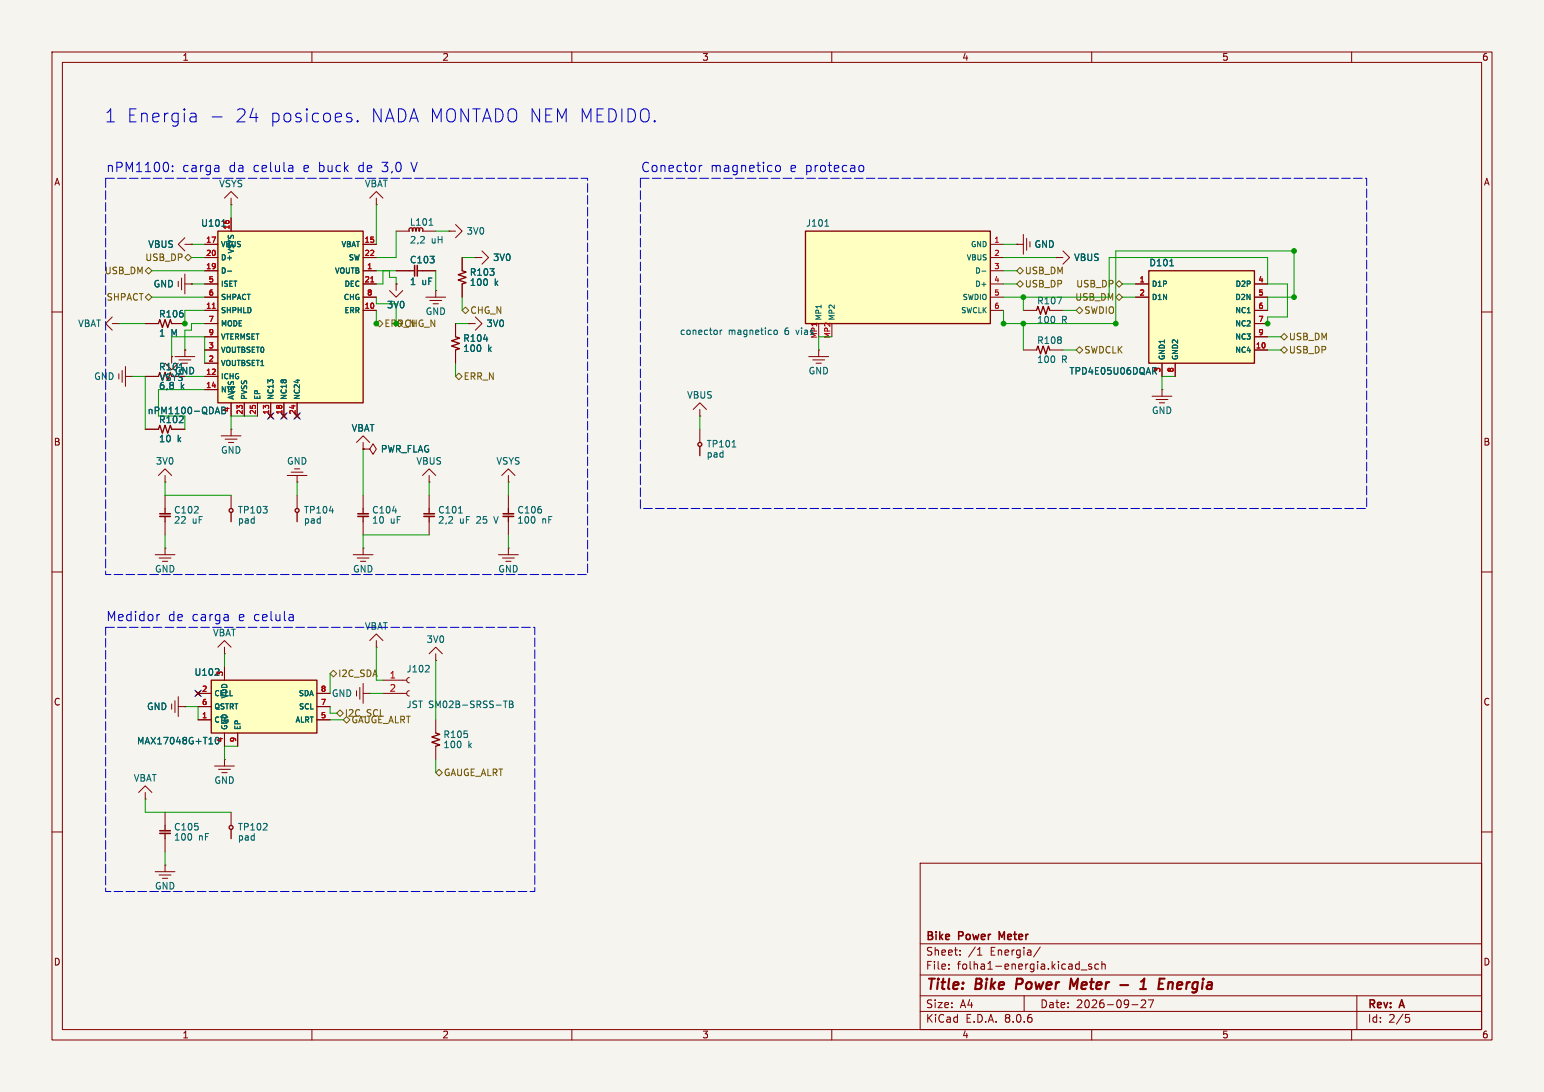
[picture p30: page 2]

1 Energia - 24 posicoes. NADA MONTADO NEM MEDIDO.

nPM1100: carga da celula e buck de 3,0 V

4 ALRT 5 QSTRT 6 SCL 7 SDA 8 EP

Id: 2/5 Title: Bike Power Meter - 1 Energia

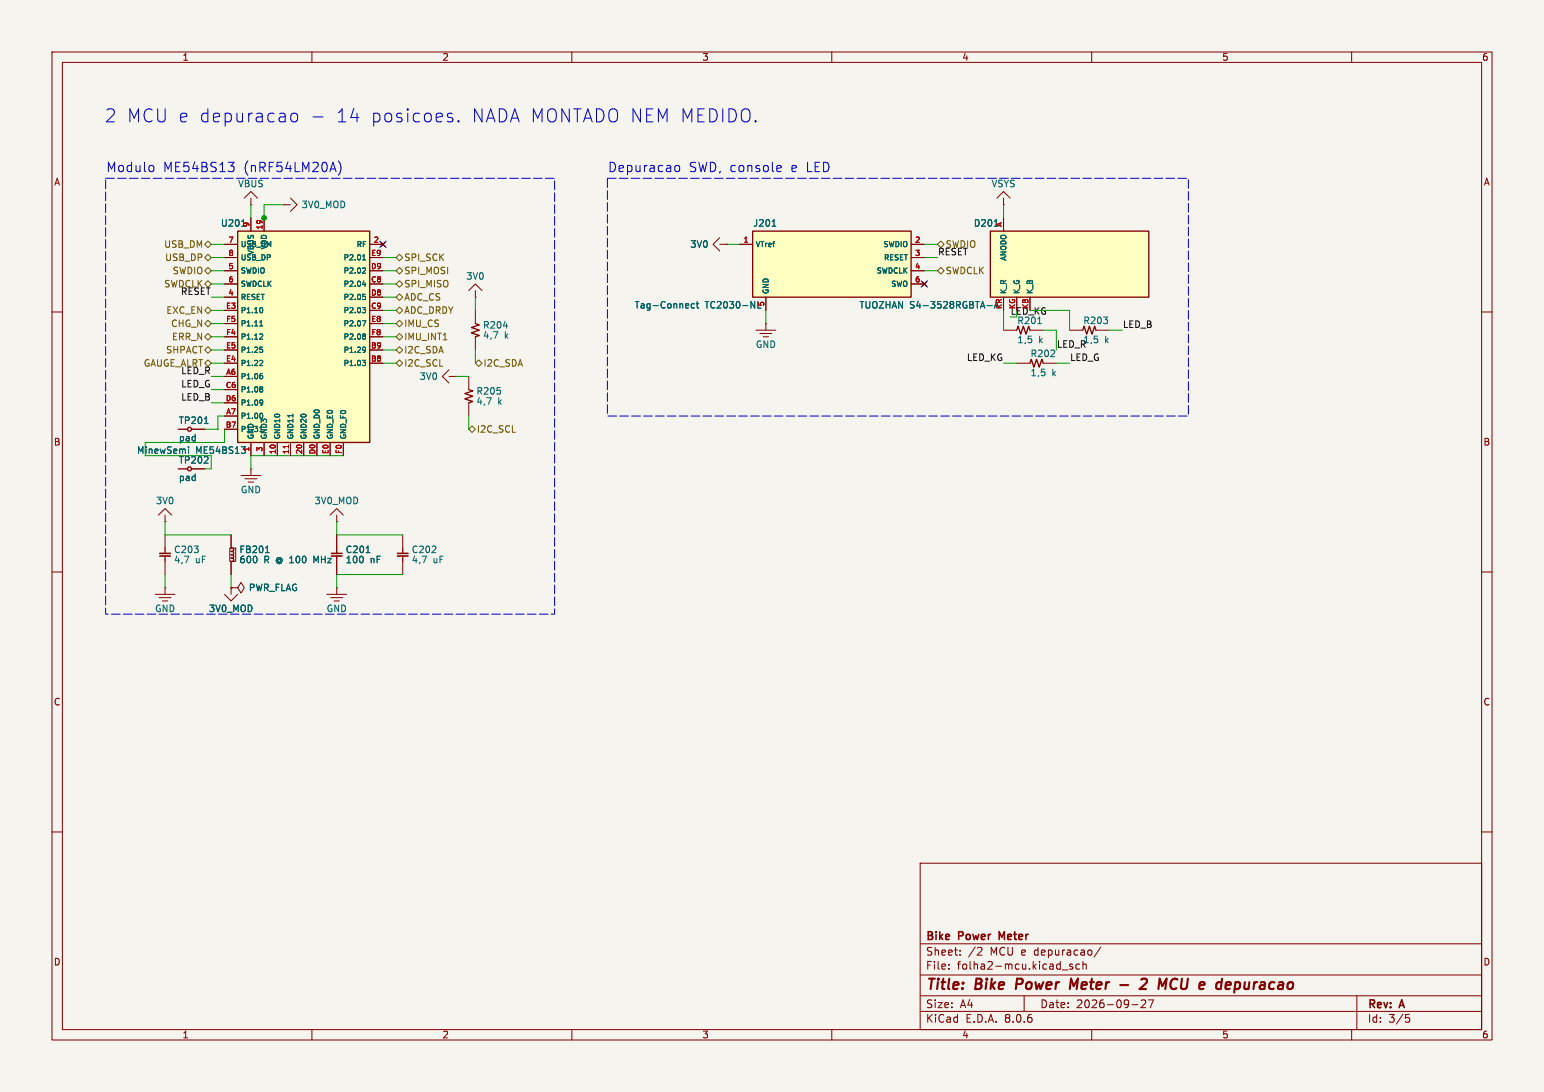
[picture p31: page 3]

5 SWO 6 J201 Tag-Connect TC2030-NL ANODO

A K_B KB K_G KG K_R KR D201 TUOZHAN S4-3528RGBTA-A R202

3 RESET 4 SWDIO 5 SWDCLK 6 USB_DM 7 USB_DP 8 VBUS

Id: 3/5 Title: Bike Power Meter - 2 MCU e depuracao



Id: 5/5 Title: Bike Power Meter - 4 Sensores

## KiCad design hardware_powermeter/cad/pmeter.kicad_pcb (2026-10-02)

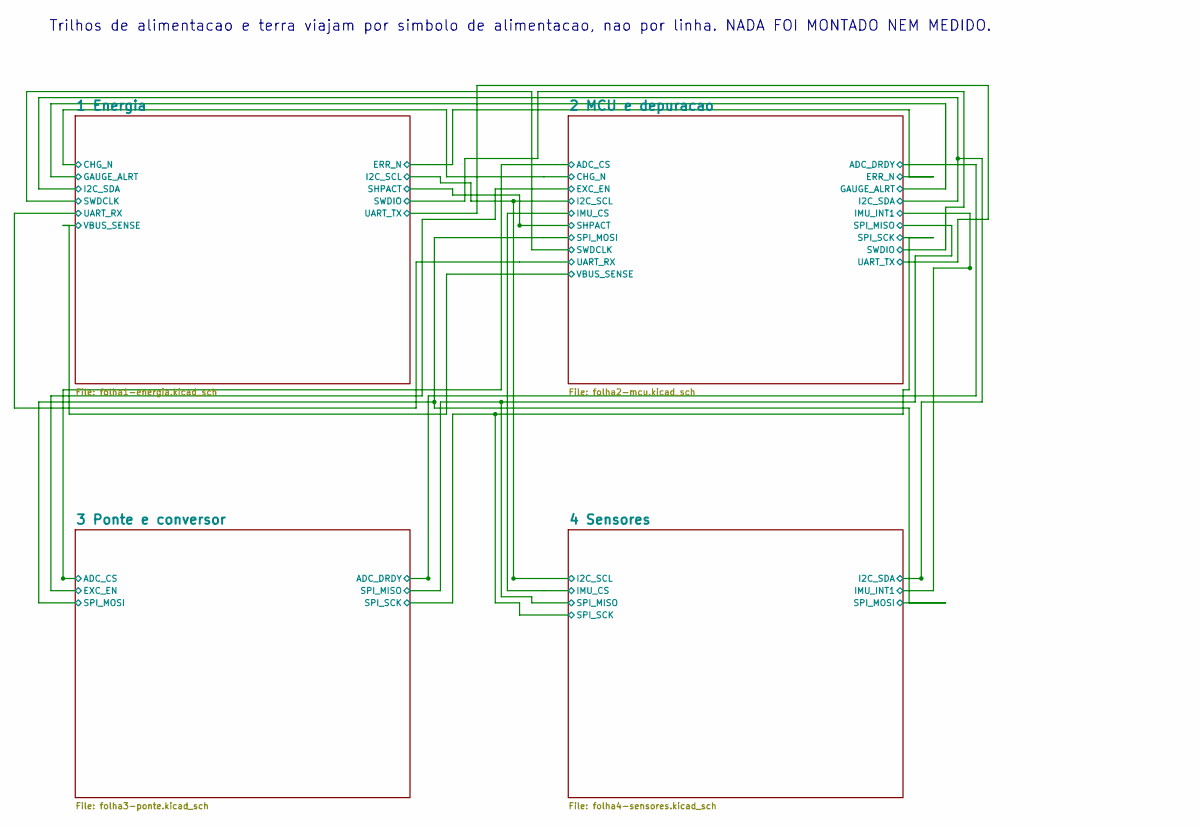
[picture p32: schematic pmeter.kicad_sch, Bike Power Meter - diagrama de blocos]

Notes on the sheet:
Trilhos de alimentacao e terra viajam por simbolo de alimentacao, nao por linha. NADA FOI MONTADO NEM MEDIDO.

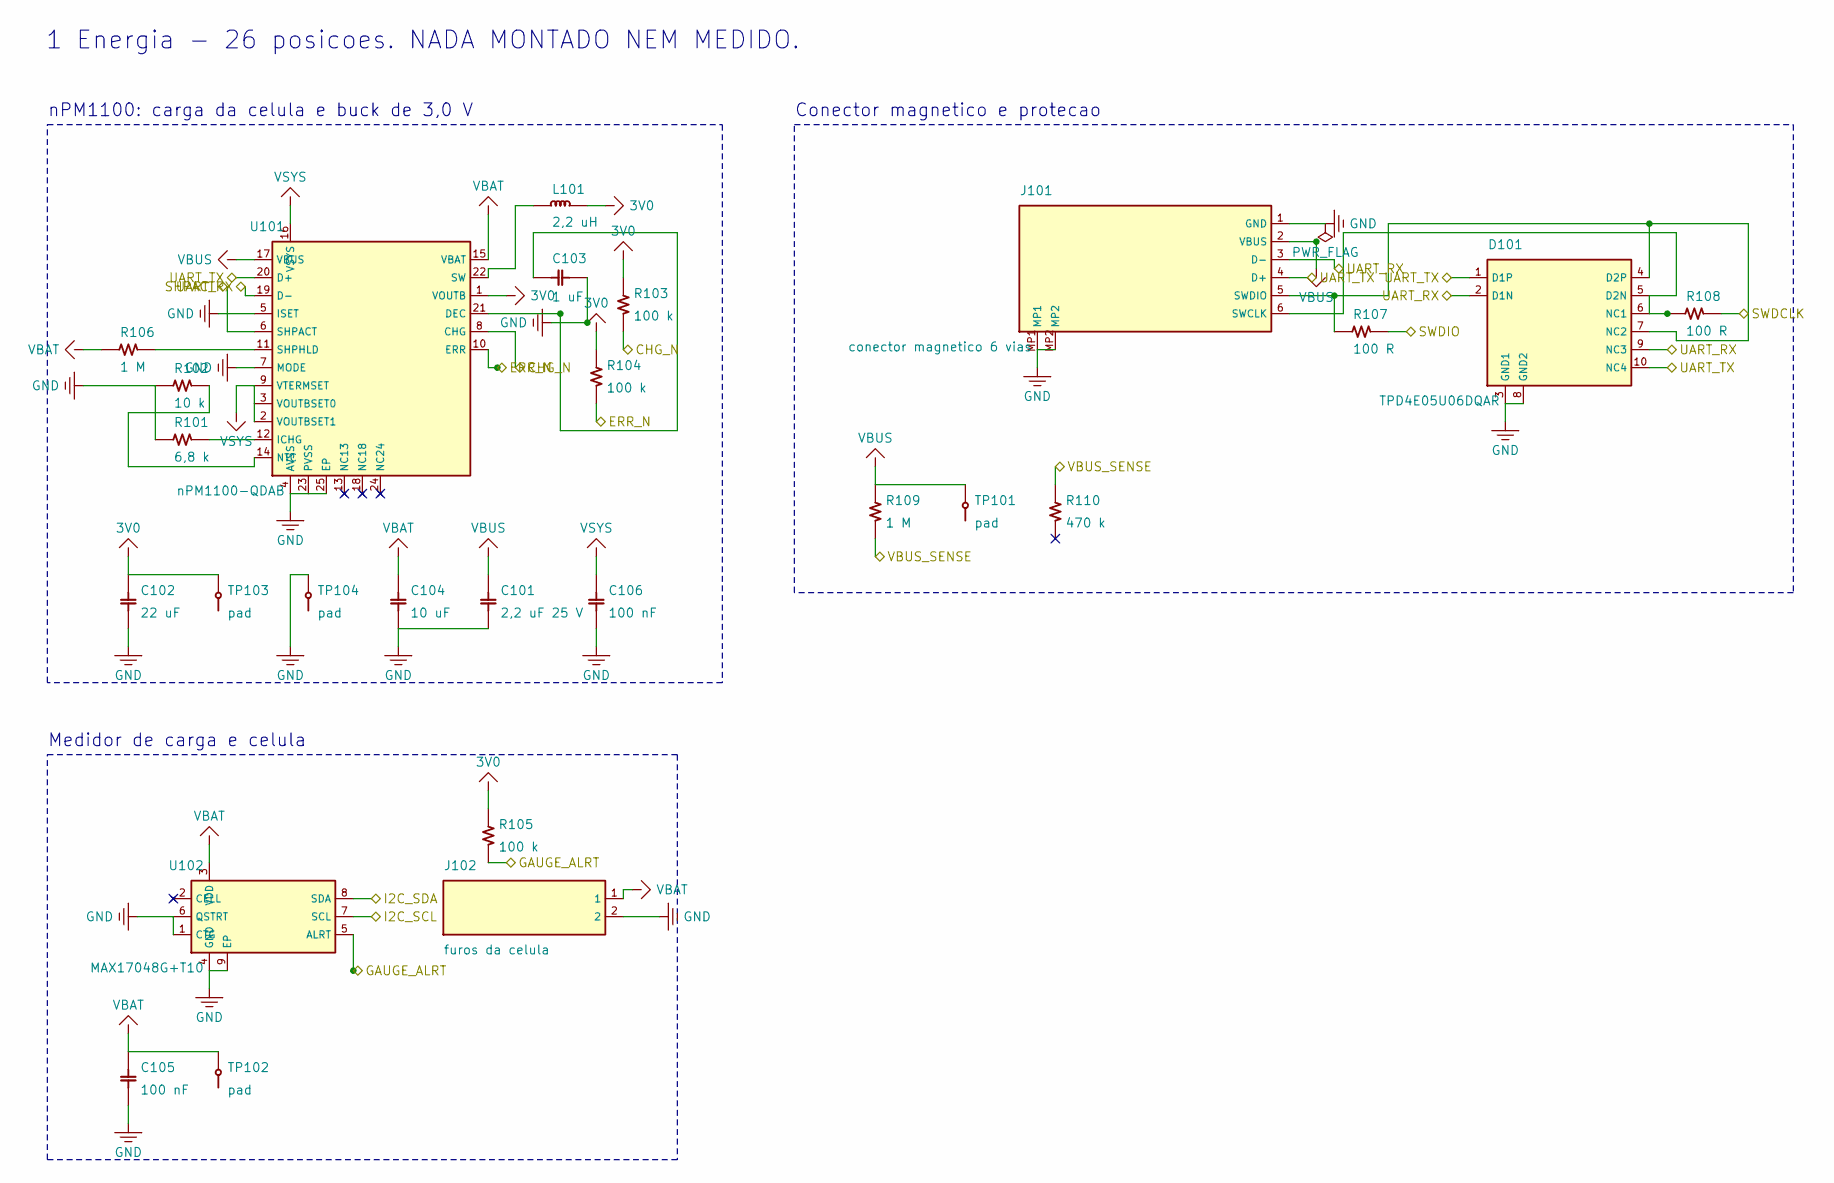
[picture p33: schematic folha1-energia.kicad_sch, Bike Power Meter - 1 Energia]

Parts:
C101: 2,2 uF 25 V; C_0603_1608Metric
C102: 22 uF; C_0603_1608Metric
C103: 1 uF; C_0402_1005Metric
C104: 10 uF; C_0603_1608Metric
C105, C106: 100 nF; C_0402_1005Metric
D101: TPD4E05U06DQAR; TPD4E05U06_USON-10_1x2.5mm_P0.5mm
J101: conector magnetico 6 vias; Pogo_Magnetico_6P_2x3_P2.5mm
J102: furos da celula; JST_SH_SM02B-SRSS-TB_1x02-1MP_P1.00mm_Horizontal
L101: 2,2 uH; L_0805_2012Metric
R101: 6,8 k; R_0402_1005Metric
R102: 10 k; R_0402_1005Metric
R103, R104, R105: 100 k; R_0402_1005Metric
R106, R109: 1 M; R_0402_1005Metric
R107, R108: 100 R; R_0402_1005Metric
R110: 470 k; R_0402_1005Metric
TP101, TP102, TP103, TP104: pad; TestPoint_Pad_D1.0mm
U101: nPM1100-QDAB; QFN-24-1EP_4x4mm_P0.5mm_EP2.7x2.7mm
U102: MAX17048G+T10; TDFN-8-1EP_2x2mm_P0.5mm_EP0.8x1.2mm

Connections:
3V0: C102.1, L101.2, R103.1, R104.1, R105.1, TP103.1, U101.1 (VOUTB); also elsewhere on the board
BUCK_SW: L101.1, U101.22 (SW)
CHG_N: R103.2, U101.8 (CHG); also elsewhere on the board
DEC: C103.1, U101.21 (DEC)
ERR_N: R104.2, U101.10 (ERR); also elsewhere on the board
GAUGE_ALRT: R105.2, U102.5 (ALRT); also elsewhere on the board
GND: C101.2, C102.2, C103.2, C104.2, C105.2, C106.2, D101.3 (GND1), D101.8 (GND2), J101.1 (GND), J101.MP1, J101.MP2, J102.2, R101.2, R102.2, TP104.1, U101.4 (AVSS), U101.5 (ISET), U101.7 (MODE), U101.23 (PVSS), U101.25 (EP), U102.1 (CTG), U102.4 (GND), U102.6 (QSTRT), U102.9 (EP); also elsewhere on the board
I2C_SCL: U102.7 (SCL); also elsewhere on the board
I2C_SDA: U102.8 (SDA); also elsewhere on the board
ICHG: R101.1, U101.12 (ICHG)
NTC: R102.1, U101.14 (NTC)
SHPACT: U101.6 (SHPACT); also elsewhere on the board
SHPHLD: R106.2, U101.11 (SHPHLD)
SWCLK_J: D101.5 (D2N), D101.6 (NC1), J101.6 (SWCLK), R108.1
SWDCLK: R108.2; also elsewhere on the board
SWDIO: R107.2; also elsewhere on the board
SWDIO_J: D101.4 (D2P), D101.7 (NC2), J101.5 (SWDIO), R107.1
UART_RX: D101.2 (D1N), D101.9 (NC3), J101.3 (D-), U101.19 (D-); also elsewhere on the board
UART_TX: D101.1 (D1P), D101.10 (NC4), J101.4 (D+), U101.20 (D+); also elsewhere on the board
VBAT: C104.1, C105.1, J102.1, R106.1, TP102.1, U101.15 (VBAT), U102.3 (VDD)
VBUS: C101.1, J101.2 (VBUS), R109.1, TP101.1, U101.17 (VBUS)
VBUS_SENSE: R109.2, R110.1; also elsewhere on the board
VSYS: C106.1, U101.2 (VOUTBSET1), U101.3 (VOUTBSET0), U101.9 (VTERMSET), U101.16 (VSYS); also elsewhere on the board

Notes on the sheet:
Conector magnetico e protecao
nPM1100: carga da celula e buck de 3,0 V
Medidor de carga e celula
1 Energia - 26 posicoes. NADA MONTADO NEM MEDIDO.

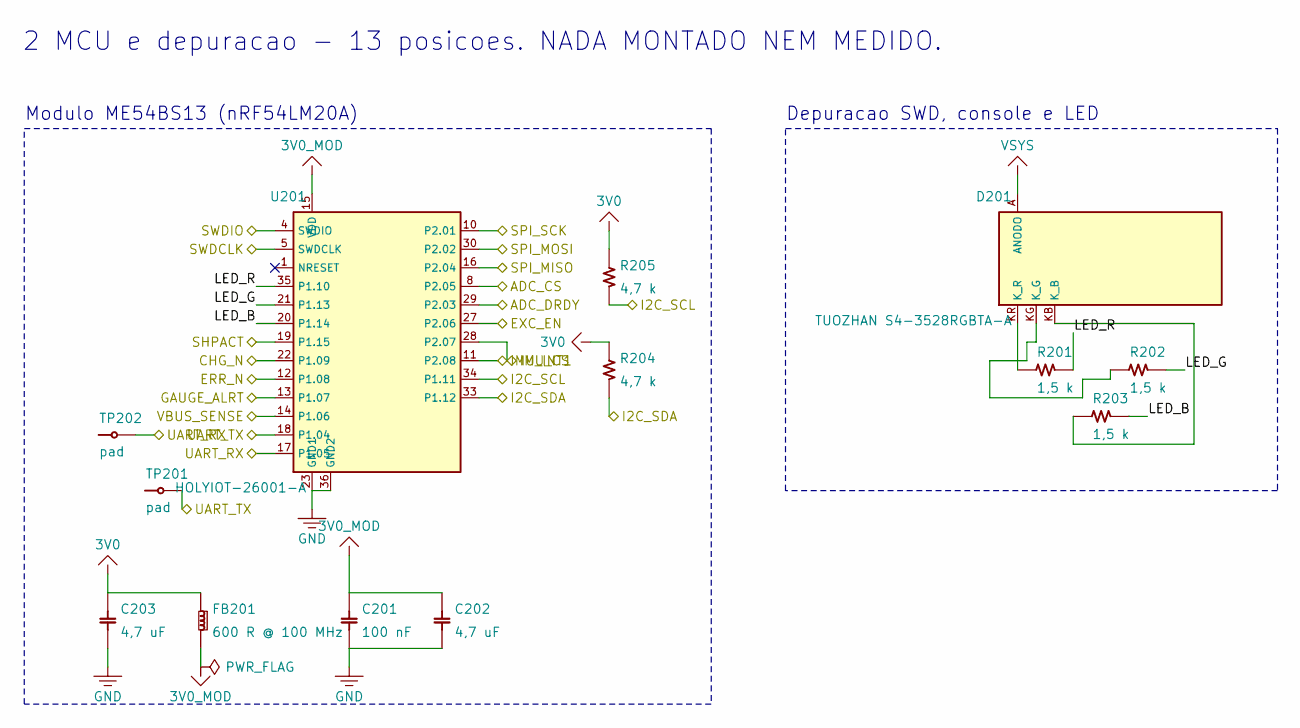
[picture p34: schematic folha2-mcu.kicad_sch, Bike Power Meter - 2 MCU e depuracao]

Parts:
C201: 100 nF; C_0402_1005Metric
C202, C203: 4,7 uF; C_0603_1608Metric
D201: TUOZHAN S4-3528RGBTA-A; LED_RGB_3528_3.5x2.8mm
FB201: 600 R @ 100 MHz; L_0603_1608Metric
R201, R202, R203: 1,5 k; R_0402_1005Metric
R204, R205: 4,7 k; R_0402_1005Metric
TP201, TP202: pad; TestPoint_Pad_D1.0mm
U201: HOLYIOT-26001-A; HOLYIOT_26001A_10x12.5mm

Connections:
3V0: C203.1, FB201.1, R204.1, R205.1; also elsewhere on the board
3V0_MOD: C201.1, C202.1, FB201.2, U201.15 (VDD)
ADC_CS: U201.8 (P2.05); also elsewhere on the board
ADC_DRDY: U201.29 (P2.03); also elsewhere on the board
CHG_N: U201.22 (P1.09); also elsewhere on the board
ERR_N: U201.12 (P1.08); also elsewhere on the board
EXC_EN: U201.27 (P2.06); also elsewhere on the board
GAUGE_ALRT: U201.13 (P1.07); also elsewhere on the board
GND: C201.2, C202.2, C203.2, U201.23 (GND), U201.36 (GND); also elsewhere on the board
I2C_SCL: R205.2, U201.34 (P1.11); also elsewhere on the board
I2C_SDA: R204.2, U201.33 (P1.12); also elsewhere on the board
IMU_CS: U201.28 (P2.07); also elsewhere on the board
IMU_INT1: U201.11 (P2.08); also elsewhere on the board
LED_B: R203.2, U201.20 (P1.14)
LED_G: R202.2, U201.21 (P1.13)
LED_KB: D201.KB (K_B), R203.1
LED_KG: D201.KG (K_G), R202.1
LED_KR: D201.KR (K_R), R201.1
LED_R: R201.2, U201.35 (P1.10)
SHPACT: U201.19 (P1.15); also elsewhere on the board
SPI_MISO: U201.16 (P2.04); also elsewhere on the board
SPI_MOSI: U201.30 (P2.02); also elsewhere on the board
SPI_SCK: U201.10 (P2.01); also elsewhere on the board
SWDCLK: U201.5 (SWDCLK); also elsewhere on the board
SWDIO: U201.4 (SWDIO); also elsewhere on the board
UART_RX: TP202.1, U201.17 (P1.05); also elsewhere on the board
UART_TX: TP201.1, U201.18 (P1.04); also elsewhere on the board
VBUS_SENSE: U201.14 (P1.06); also elsewhere on the board
VSYS: D201.A (ANODO); also elsewhere on the board

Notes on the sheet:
Modulo ME54BS13 (nRF54LM20A)
Depuracao SWD, console e LED
2 MCU e depuracao - 13 posicoes. NADA MONTADO NEM MEDIDO.

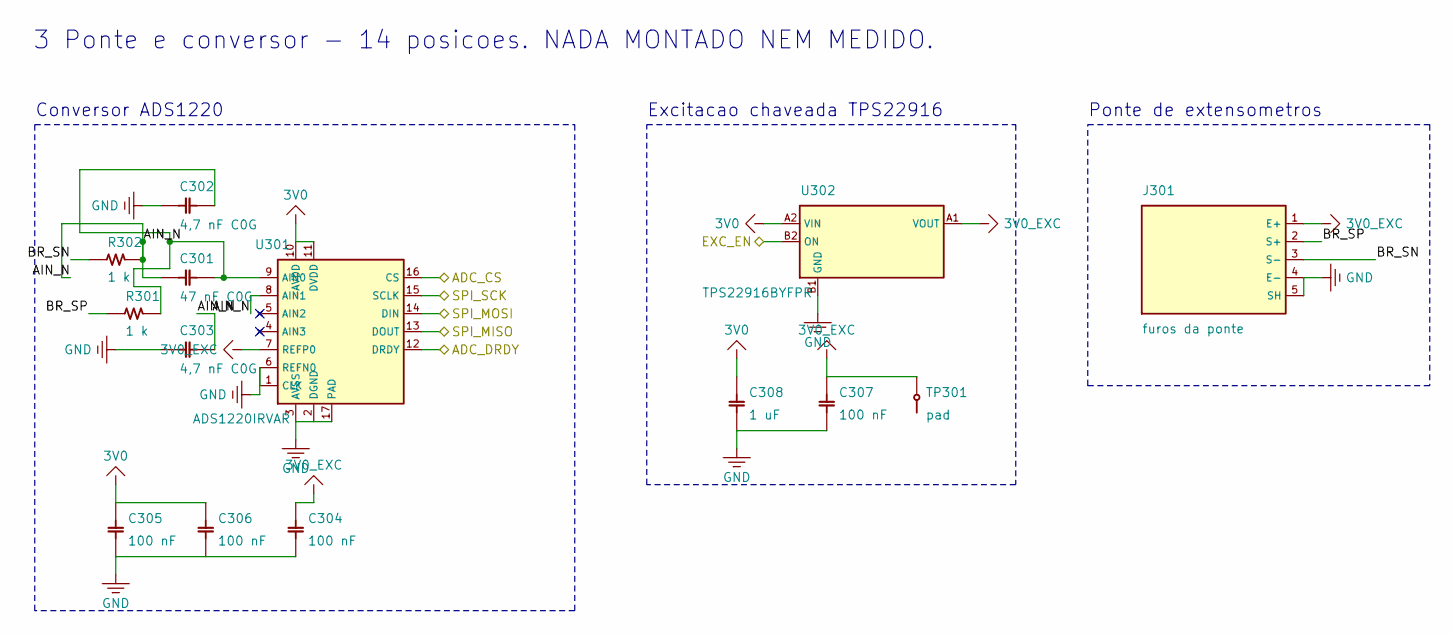
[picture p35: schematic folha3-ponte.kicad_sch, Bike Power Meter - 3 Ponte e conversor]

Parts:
C301: 47 nF C0G; C_0402_1005Metric
C302, C303: 4,7 nF C0G; C_0402_1005Metric
C304, C305, C306, C307: 100 nF; C_0402_1005Metric
C308: 1 uF; C_0402_1005Metric
J301: furos da ponte; Furos_Ponte_5x1.5mm_P2mm
R301, R302: 1 k; R_0402_1005Metric
TP301: pad; TestPoint_Pad_D1.0mm
U301: ADS1220IRVAR; Texas_RVA_VQFN-16-1EP_3.5x3.5mm_P0.5mm_EP2.14x2.14mm
U302: TPS22916BYFPR; TPS22916_DSBGA-4_0.78x0.78mm_P0.4mm

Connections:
3V0: C305.1, C306.1, C308.1, U301.10 (AVDD), U301.11 (DVDD), U302.A2 (VIN); also elsewhere on the board
3V0_EXC: C304.1, C307.1, J301.1 (E+), TP301.1, U301.7 (REFP0), U302.A1 (VOUT)
ADC_CS: U301.16 (CS); also elsewhere on the board
ADC_DRDY: U301.12 (DRDY); also elsewhere on the board
AIN_N: C301.2, C303.1, R302.2, U301.8 (AIN1)
AIN_P: C301.1, C302.1, R301.2, U301.9 (AIN0)
BR_SN: J301.3 (S-), R302.1
BR_SP: J301.2 (S+), R301.1
EXC_EN: U302.B2 (ON); also elsewhere on the board
GND: C302.2, C303.2, C304.2, C305.2, C306.2, C307.2, C308.2, J301.4 (E-), J301.5 (SH), U301.1 (CLK), U301.2 (DGND), U301.3 (AVSS), U301.6 (REFN0), U301.17 (PAD), U302.B1 (GND); also elsewhere on the board
SPI_MISO: U301.13 (DOUT); also elsewhere on the board
SPI_MOSI: U301.14 (DIN); also elsewhere on the board
SPI_SCK: U301.15 (SCLK); also elsewhere on the board

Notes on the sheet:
Ponte de extensometros
Excitacao chaveada TPS22916
Conversor ADS1220
3 Ponte e conversor - 14 posicoes. NADA MONTADO NEM MEDIDO.

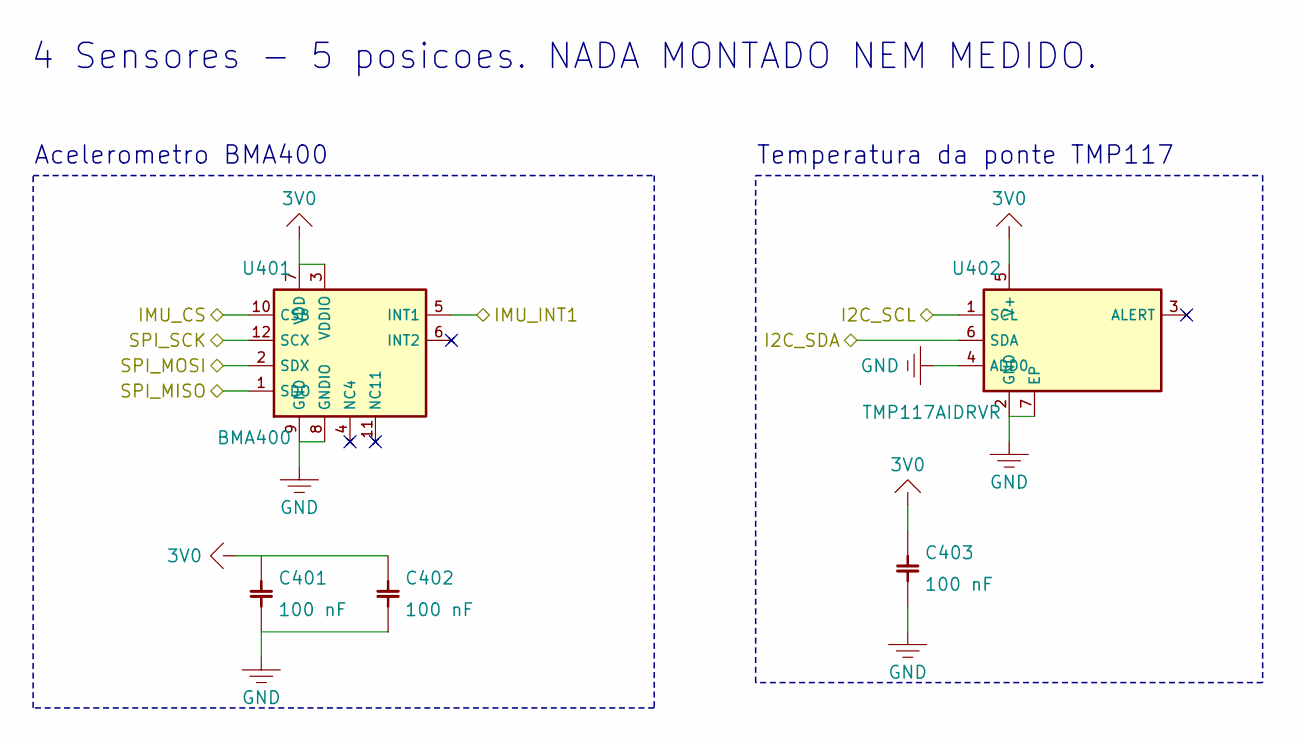
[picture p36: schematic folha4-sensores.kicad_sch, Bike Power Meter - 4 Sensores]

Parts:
C401, C402, C403: 100 nF; C_0402_1005Metric
U401: BMA400; LGA-12_2x2mm_P0.5mm
U402: TMP117AIDRVR; WSON-6-1EP_2x2mm_P0.65mm_EP1x1.6mm

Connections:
3V0: C401.1, C402.1, C403.1, U401.3 (VDDIO), U401.7 (VDD), U402.5 (V+); also elsewhere on the board
GND: C401.2, C402.2, C403.2, U401.8 (GNDIO), U401.9 (GND), U402.2 (GND), U402.4 (ADD0), U402.7 (EP); also elsewhere on the board
I2C_SCL: U402.1 (SCL); also elsewhere on the board
I2C_SDA: U402.6 (SDA); also elsewhere on the board
IMU_CS: U401.10 (CSB); also elsewhere on the board
IMU_INT1: U401.5 (INT1); also elsewhere on the board
SPI_MISO: U401.1 (SDO); also elsewhere on the board
SPI_MOSI: U401.2 (SDX); also elsewhere on the board
SPI_SCK: U401.12 (SCX); also elsewhere on the board

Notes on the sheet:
Acelerometro BMA400
Temperatura da ponte TMP117
4 Sensores - 5 posicoes. NADA MONTADO NEM MEDIDO.

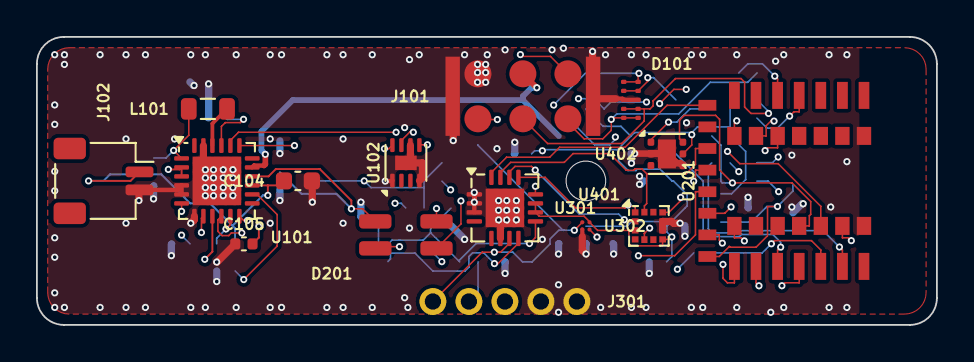
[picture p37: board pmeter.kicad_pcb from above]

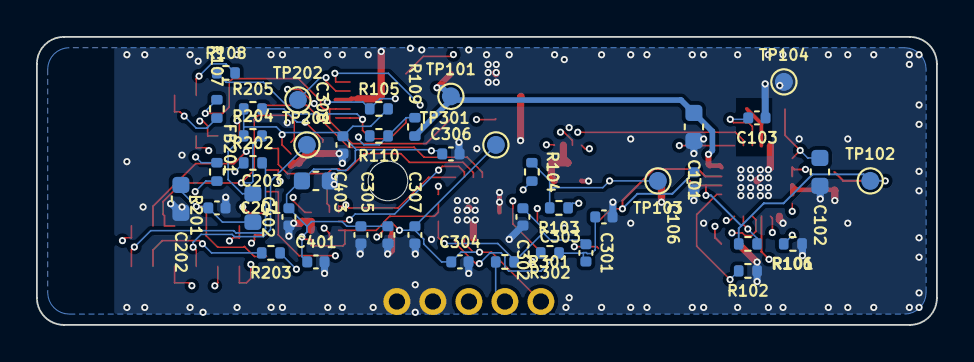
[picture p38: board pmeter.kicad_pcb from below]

Board: 4 copper layers, 50.0 x 16.0 mm, 58 parts (43 on the bottom side), 43 nets.

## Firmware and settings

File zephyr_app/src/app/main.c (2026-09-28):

/**
 * @file main.c
 * @brief Boot of the bike power meter (docs/04)
 *
 * main() prepares what the services share (task watchdog, settings) and
 * starts the service threads in the order of docs/04: power first, then
 * sample, motion, compute, radio and the USB serial. Then it tells the
 * system machine that the boot is over and returns; the services run on
 * their own.
 */

#include <zephyr/kernel.h>
#include <zephyr/logging/log.h>

#include "app/app_services.h"
#include "app/app_svc.h"
#include "app/pm_store.h"
#include "app_types.h"

LOG_MODULE_REGISTER(main, CONFIG_LOG_DEFAULT_LEVEL);

int main(void)
{
    LOG_INF("%s %s", APP_NAME, APP_VERSION_STR);

    /* a watchdog that survived a soft reset keeps counting */
    app_wdt_feed_if_running();

    pm_store_init();

    app_wdt_feed_if_running();
    app_wdt_init();

    power_svc_start();
    sample_svc_start();
    motion_svc_start();
    compute_svc_start();
    radio_svc_start();
#if defined(CONFIG_USB_DEVICE_STACK_NEXT)
    usb_svc_start();
#else
    serial_svc_start();
#endif

    power_svc_ready();
    LOG_INF("services started");
    return 0;
}

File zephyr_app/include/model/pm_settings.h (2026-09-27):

/**
 * @file pm_settings.h
 * @brief The configuration of the meter: limits, defaults, the versioned
 *        blob it is stored and sent as, and the text keys of the
 *        configuration commands (docs/05, Serviço de configuração)
 *
 * The blob is explicit, field by field, little-endian, with the version in
 * front and a CRC-16 at the end: the same bytes go to the settings
 * subsystem of Zephyr and to the configuration characteristic, and the
 * host tests fix them byte by byte. A blob of another version is refused;
 * a migration is written when a version 2 exists.
 */

#ifndef PM_SETTINGS_H
#define PM_SETTINGS_H

#include <stdbool.h>
#include <stddef.h>
#include <stdint.h>

#include "model/bridge_calc.h"
#include "model/pm_types.h"

#ifdef __cplusplus
extern "C" {
#endif

#define PM_SETTINGS_VERSION         1U
/** Name of the meter, with its terminator ("PM-" and up to 8 characters) */
#define PM_SETTINGS_NAME_LEN        12U
/** Size of the blob of this version */
#define PM_SETTINGS_WIRE_LEN        60U

/* Limits (docs/02, Requisitos) */
#define PM_CRANK_MIN_HALF_MM        200U    /**< 100 mm */
#define PM_CRANK_MAX_HALF_MM        500U    /**< 250 mm */
#define PM_RADIUS_MIN_MM            10U
#define PM_RADIUS_MAX_MM            200U
#define PM_AUTO_ZERO_STEP_MAX       1677721L /**< 20 % of the full scale */

/** The side, as the CPS sensor location */
#define PM_SIDE_LEFT                5U
#define PM_SIDE_RIGHT               6U

struct pm_settings {
    uint16_t crank_length_half_mm;  /**< 0,5 mm, as the CPS carries it */
    uint16_t sensor_radius_mm;      /**< accelerometer to axle */
    uint8_t side;                   /**< PM_SIDE_LEFT or PM_SIDE_RIGHT */
    int8_t tangential_sign;         /**< +1 or -1 */
    struct bridge_cal cal;          /**< slope 0: not calibrated */
    uint16_t sample_rate_sps;       /**< ADS1220 normal mode: 20, 45, 90, 175, 330, 600, 1000 */
    bool auto_zero;                 /**< revise the zero while the crank rests */
    int32_t auto_zero_max_step;     /**< largest auto zero accepted, counts */
    uint16_t ant_device_number;     /**< 0: derived from the radio address at boot */
    uint16_t cal_year;              /**< factory calibration date, 0 0 0 when unset */
    uint8_t cal_month;
    uint8_t cal_day;
    char name[PM_SETTINGS_NAME_LEN];
};

/**
 * @brief The factory defaults: 172,5 mm, 50 mm, left, +1, no calibration, 175 SPS,
 *        auto zero of 0,5 % of the full scale, no ANT number, "PM"
 */
void pm_settings_defaults(struct pm_settings *s);

/**
 * @brief Check every field against its limits
 * @return PM_OK, or PM_EINVAL naming nothing (the command layer reports the key)
 */
pm_err_t pm_settings_validate(const struct pm_settings *s);

/**
 * @brief The bridge has a slope: torque can be reported
 */
bool pm_settings_calibrated(const struct pm_settings *s);

/**
 * @brief Write the blob
 * @return PM_SETTINGS_WIRE_LEN, or 0 when @p buf is too small
 */
size_t pm_settings_serialize(const struct pm_settings *s, uint8_t *buf, size_t len);

/**
 * @brief Read a blob
 * @return PM_OK; PM_EINVAL on a wrong length, version or CRC, or on values out of range
 */
pm_err_t pm_settings_deserialize(const uint8_t *buf, size_t len, struct pm_settings *s);

/**
 * @brief CRC-16/CCITT-FALSE (poly 0x1021, init 0xFFFF), the one of the blob
 */
uint16_t pm_crc16(const uint8_t *data, size_t len);

/**
 * @brief The i-th text key, or NULL past the last one
 */
const char *pm_settings_key(size_t i);

/**
 * @brief Set one field from its text value, as $CFG,SET does
 * @return PM_OK; PM_EINVAL for an unknown key or a value out of range (nothing changes)
 */
pm_err_t pm_settings_set_text(struct pm_settings *s, const char *key, const char *value);

/**
 * @brief Print one field as text, as $CFG,GET does
 * @return Characters written (without the terminator), 0 for an unknown key or a short buffer
 */
size_t pm_settings_get_text(const struct pm_settings *s, const char *key, char *buf, size_t len);

#ifdef __cplusplus
}
#endif

#endif /* PM_SETTINGS_H */

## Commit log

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2026-09-27 docs(docs): requirements, firmware architecture, protocols and measurement method
    Requirements with the product-class floor (20 g, 50 h, 0-2000 W, IP),
    the block diagram and rails, the consumption budget from the datasheets,
    the board and pod constraints; the service and event architecture, the
    system state machine and the model modules with their test plan; the
    BLE Cycling Power, configuration service, ANT+ and update protocols; and
    the measurement chain from bridge to watts with the calibration
    procedures, the temperature model, the error budget and the references
    (TI SBAA532A, Micro-Measurements guide, NIST, GUM, Crossref papers).
    Product makers are no longer named anywhere in the reposit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
2026-09-27 feat(model): bridge, crank angle, revolution power and calibration with host tests
    The four measurement modules of docs/06 in plain C, with no Zephyr type,
    each with its Unity suite in tests/host and a gcov line coverage of 100 %
    (tools/fw/coverage.py, run by host_tests.sh coverage, fails below 95 %).
    bridge_calc turns an ADS1220 code into torque with the zero, the slope
    and the temperature model, through a median of three; rev_power
    integrates torque over angle per revolution and reports the CPS units
    (1/32 N.m, kJ, 1/1024 s); calib does the zero with its stability rule,
    the slope by least squares through the origin with residual and
    hysteresis, the torque of a hung mass and the temperatur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
    [calib.h]
2026-09-27 feat(model): CPS bytes, settings blob, text commands, health flags and the system machine
    The five modules the services will drive, in plain C with host tests
    (67 cases) and every line covered.
    cps_encode builds the Cycling Power Measurement with its content mask,
    the Feature, the Control Point requests and responses and the Vector,
    byte by byte as Cycling Power Service 1.1 lays them out; pm_settings
    holds the configuration with every limit, a 60-byte versioned blob with
    a CRC-16 (explicit little-endian fields instead of CBOR, so the same
    bytes go to the settings subsystem and to the characteristic and the
    tests fix them), and the text keys of $CFG; pm_cmd parses the $ lines of
    docs/05 and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
    [cps_encode.h]
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2026-09-27 feat(build): MCUboot serial recovery over the USB of the connector, and $SLEEP as an event
    The pod has no button, so at every boot MCUboot brings the USB up and
    waits one second for a recovery request on its own CDC ACM port (mcumgr
    over SMP) before booting the application; the nRF54LM20A takes the new
    USB device stack for it. The bootloader with the USB stack does not fit
    the 64 KB of the vendor layout (it overflowed by 23.668 B), so the layout
    of the project gives it 96 KB and each image slot 904 KB, in the three
    devicetrees that must agree: the pod board, the DK overlay and
    sysbuild/mcuboot.overlay.
    That overlay also repeats zephyr,code-partition = &boot_partition: once
    a sysbuild/mcuboo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
    [power_svc.c]
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2026-09-27 feat(board): check the schematic against the same pin table as the devicetree
    board_check.py compared the devicetree with the pin table of docs/02 and
    stopped there, while the schematic followed the same table by assertion
    only: nets.py says so in its header and nothing measured it. A board
    fabricated with one pin map and firmware compiled with another is found
    on the bench, with the parts already soldered.
    It now parses hardware_powermeter/cad/nets.py and compares both ways:
    every Px.yy of the table is on a net with the module, every module pin of
    the schematic is in the table, and no module pin sits on two nets, which
    would be a short. Missing file or no module pin is reported as "could n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
    [board_check.py]
2026-09-27 fix(rf): require a bonded link for what changes the meter, and make DFU reachable
    Two defects in the same place, both invisible to the build.
    The SMP service took Zephyr's default, which with CONFIG_BT_SMP=y is
    MCUMGR_TRANSPORT_BT_PERM_RW_AUTHEN: authenticated pairing, security
    level 3. The pod has no display and no keyboard, so its IO capability is
    NoInputNoOutput, pairing is always Just Works and the link stops at
    level 2. The characteristic could never be written from a phone, so the
    update over BLE would simply not work, and nothing said so. Both board
    files now set MCUMGR_TRANSPORT_BT_PERM_RW_ENCRYPT, the level the device
    can actually reach. Verified in the generated .config.
    The conf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
2026-09-27 docs(docs): state what the board owes the accelerometer axes
    CONFIG_PM_IMU_AXIS_RADIAL and _TANGENTIAL default to X and Y, and the
    Kconfig help admits it is "a fact of the board, to be confirmed". No
    document carried that fact, so nothing could confirm it and nothing
    would fail if the board came out otherwise. Swapping radial for
    tangential feeds the centripetal term into the cadence and the power
    comes out wrong with no error anywhere.
    docs/02 now carries the requirement axis by axis, with the sign
    convention measured in section 8.2 of BST-BMA400-DS000-14, and names the
    link still missing: whether the +X of the library footprint is the +X of
    the package, which depends on the pin 1 corner,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
2026-09-27 feat(hardware): port the CAD chain and generate the schematic
    The bike computer's KiCad generators, brought over with this board's own
    tables: 57 parts with every pin read off its datasheet, 45 nets, four
    functional sheets and a root block diagram. check_sch.py runs the ERC,
    exports the netlist and compares it with nets.py pin by pin; it reports
    no error.
    Two rules are new. TX1 and TX2 (sch_legivel.py) measure the exported PDF
    word by word and fail when two pieces of text print on the same spot or
    when a reference lands inside a symbol's body - legibility is what the
    ERC can never see. They found 81 overlapping pairs, which led to the
    cause: a 1,27 mm field really occupies 2,43 mm in the pl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
    [folha1-energia.kicad_sch, folha2-mcu.kicad_sch, folha3-ponte.kicad_sch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]
2026-09-27 feat(hardware): place, route and check the 60 x 16 mm board
    Four layers, 0,8 mm, every part on the front face because the cell lies
    under the board inside the pod. 546 segments, 179 vias, 77 of the 110
    connections closed, and the DRC reports zero errors. It is not routed
    and cannot be fabricated; 08 says exactly what is open.
    The size is measured, not chosen: the placer was run at one length after
    another and 48 x 16, the target, leaves 18 parts without a spot.
    Three corrections to the router, each measured on this board. A net's
    connections now grow from the pin nearest to what is already drawn,
    instead of following the pad list from one end of the board to the
    other. The neck inside a pa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
    [contorno.dxf, pmeter.kicad_pcb, zonas.dxf]
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2026-09-27 fix(app): the accelerometer axes were inverted, measured against the board
    CONFIG_PM_IMU_AXIS_RADIAL and _TANGENTIAL defaulted to X and Y because
    nobody had measured which package axis runs along the crank arm. The
    board's dry run now measures it, reading the orientation table of
    BST-BMA400-DS000-14 section 8.2 against the pin 1 corner of the U401
    footprint and the part's rotation: the package's Y runs along the arm
    and its X across it, the opposite of the guess, and the positive Y
    points at the axle end of the board. Radial becomes Y, tangential X, and
    the radial sign -1 so that radial grows outward as the model wants.
    Inverted, the centripetal term lands inside the cadence and the power i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
2026-09-27 docs(docs): 5 kOhm gauges, the pod back to the target envelope, and the licence
    Three decisions from the owner on 2026-09-27.
    Transducer-class gauges of 5 kOhm instead of 1 kOhm. The bridge draws
    0,6 mA instead of 3,0 and the total while pedalling 1,5 mA instead of
    3,9, so the 50 hour requirement closes on a 100 mAh cell instead of
    failing on 150. Resolution does not pay for it: the thermal noise of
    5 kOhm over 10 Hz is 0,03 uV against the converter's own 0,26 uV. What
    is still to confirm is that a 45 degree shear pattern exists at that
    resistance; if it does not, the way out is the converter's duty-cycle
    mode, not going back to 1 kOhm.
    The pod has to come close to 60 x 20 x 8,5 mm in all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
2026-09-28 fix(docs): the specified gauge pattern is wrong for a crank arm
    The component list asks for a 45 degree shear pattern, which is what a
    shaft torque meter uses. A crank arm is not a shaft: it is a cantilever
    loaded at its end by the pedal's tangential force, and on the flat inner
    face the two quantities live in different places. Bending strain is
    largest at the two edges and zero along the middle; shear strain is the
    opposite, largest along the middle, which is the neutral axis.
    Worked with representative numbers, aluminium, 20 x 14 mm section, 500 N
    tangential, gauge 60 mm from the pedal: the 45 degree grid reads 52
    microstrain and an axial grid at the edge reads 459, which is 8,9 times
    mor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
2026-09-28 docs(hardware): make the one-piece full bridge the choice, in the maker's words
    Four separate gauges mean four alignments, and alignment is the error the
    project's own documents call the accuracy bottleneck. A full bridge on a
    single carrier is one bonding, with the four grids already placed and
    interconnected at the factory. It was listed here as an alternative and
    becomes the choice, together with the bending pattern docs/06 argues for
    on measured grounds.
    Three things were read in the manufacturer's selection guide rather than
    recalled. It names 120, 350, 1 k and 5 kOhm and says the higher
    resistance is preferable where there is a choice, for heat, leadwire
    desensitisation and signal to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
2026-09-28 docs(docs): recalculate the budget for the resistances a one-piece bridge comes in
    The 5 kOhm decision assumed the gauge pattern would exist at 5 kOhm. The
    maker's catalogue treats "full-bridge patterns" and "high resistance
    patterns, 350 ohm to 20 kOhm" as two separate families, which is already
    a hint that the intersection may not exist, and the pattern pages are
    script-driven and would not open from this machine on 2026-09-28. So the
    answer is a number instead of a hope.
    Recalculated: 1 kOhm continuous is 3,90 mA and fails, but 1 kOhm with the
    ADS1220's duty-cycle mode is 1,40 mA, which beats 5 kOhm continuous at
    1,50, because the converter itself drops from 0,585 to 0,190 mA in that
    mod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
2026-09-28 fix(hardware): let the DRC judge the routing, and fit the pod to the board
    No stage of the router could tell whether it had connected anything. The
    negotiated-congestion stage closed announcing "96 connections, 0 contested
    cells" while eleven pads had no copper at all, among them every terminal of
    USB_DM, which was left as three loose fragments of 0.9 mm. Three separate
    defects, each measured:
    - the acceptance test compared the NUMBER of connections (n_ok_n > n_ok)
    instead of open pads;
    - accepting the negotiated answer threw away the sequential copper of the
    nets it had not routed (16 -> 12 open once inherited);
    - the inherited copper was not given to the negotiated stage as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
    [pmeter.kicad_pcb, pod-concha.stl]
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2026-09-28 feat(board): move the pod to the nRF54L15 on the HOLYIOT-26001-A
    The radio module was 26 % of the board's area in one part, and it is the
    only lever on size that moves anything. This is the swap, end to end: the
    netlist, the schematic, the outline, the placement, the board files, the
    firmware and the bootloader.
    What the SoC takes away, and what replaces it:
    - There is no USB on the nRF54L15. `usbhs` does not exist in
    nrf54l_05_10_15.dtsi, so the module has no VBUS pin either - pad 9 is
    P2.00, a plain GPIO that the cable's 5 V would destroy. The two contacts
    of the magnetic connector that carried D+ and D- now carry UART TX and
    RX: the serial port of the commands (the cal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
    [contorno.dxf, zonas.dxf]
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2026-09-28 feat(all): 114 h instead of 52, a real cell, and a pod that finally shrank
    Three things the owner pushed back on, and one arithmetic error of this
    project's own that the pushing uncovered.
    THE POD HAD NOT SHRUNK, and he was right. The board went from 51 x 16 to
    47 x 14 with the smaller module, and the pod went from 56,4 to 59,4 - the
    two closing screws had each been given a boss OUTSIDE the board, at 5,4 mm
    of length. The right-hand screw now goes THROUGH the board: a boss rises
    from the floor, a 2,00 mm neck passes through a hole, and the screw comes
    down from the lid. It can only be done on one side - a post that pierces
    the board needs floor under it with no cell, and the cell leaves an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
    [pmeter.kicad_pcb, pod-concha.stl, pod-tampa.stl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]
2026-09-28 perf(cad): rip up only what is in the way, and let the round be watched
    The owner asked twice for something this session kept failing to give him:
    a way to tell a router that is working from one that has hung, and a reason
    why a board takes over an hour. Both answers were in the same place.
    WHY IT WAS SLOW. The negotiated stage cleared `uso` and `caminhos_por_rede`
    at the top of every round and routed all 84 connections again - 30 s a
    round, and it was still at 84 connections with 110 to 198 contested cells at
    round 120 when it was stopped. PathFinder does not work that way: it rips up
    only the nets that use a contested cell, because a net nobody is fighting
    with is still legal and the hist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
    [zonas.dxf]
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2026-09-28 fix(cad): stop measuring a USB pair that is not on the board any more
    The nRF54L15 has no USB. The two contacts of the magnetic connector that
    carried D+ and D- now carry UART_TX and UART_RX, and US1 was still
    measuring the 90 ohm width of USB_DP/USB_DM -- nets that left the board.
    Same disease as ME7: failing while pointing at a part that is gone is
    worse than not measuring.
    At 115200 baud there is no pair and no impedance to hold. What still
    matters is where the two lines run, and the geometry for that already
    exists: SEM_PLANO_BUCK_SW, the bounding box of the switching node's pads
    plus 0,6 mm, cut out of every plane because it is the noisiest point on
    the board. The rule measures whether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
    [board_check.py]
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2026-09-28 feat(hardware): the board routed with zero DRC errors, and every view redrawn
    The chain ran in its documented order for the first time since the module
    swap -- make_pcb, route, fill_zones, drc, reparar, twice -- and the board
    came out with 440 segments, 153 vias, 75 connections and NO DRC errors.
    The 25 warnings are all library registration: the footprints here are
    generated, not taken from a registered library.
    What is still open, and the board cannot be fabricated until it closes:
    three signal connections with no copper (I2C_SCL, SPI_MOSI, SPI_SCK, all
    in the same stretch between the converter and the module), and seven of
    seventeen decoupling capacitors past the datasheet limit. The seco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
    [pmeter.kicad_pcb, pod-concha.stl, pod-tampa.stl]
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2026-09-29 feat(hardware): the board with the radio module actually connected
    Everything measured about routing before today measured a board where a
    quarter of the connections did not exist. With the module's pads carrying
    nets, the router has 25 more connections to make: 551 segments, 137 vias,
    81 connections, still ZERO DRC errors, and 30 unconnected items against
    the old 14 -- that 14 was flattering by omission.
    Of the 49 the router did not close, 22 are ground stitching vias the pour
    resolves. The signal ones cluster in two places and both are fine-pitch
    pad escape: the nPM1100's pins, a 0,5 mm QFN with nine nets stuck at it,
    and the module's. It is not area -- growing the board to 50 or 52 mm wa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
    [pmeter.kicad_pcb]
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2026-09-30 feat(hardware): route the board with the finer rules, and shorten the placement
    The board now carries 93 routed connections, 651 tracks and 217 vias with
    ZERO DRC errors, against 75 connections and 440 tracks before. Twenty-one
    connections are still open and the drawings say so.
    The placement gained an improvement pass. The placer was constructive -
    anchors, decoupling against the pin, the rest by waves of connectivity -
    and nobody looked at the result afterwards. The new pass does what a
    person does at the end: each movable part tries other spots nearby and
    keeps whatever shortens the half-perimeter of the nets it is on. It takes
    31.8 mm of connection off the board, and it is what let the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
    [pmeter.kicad_pcb]
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2026-09-30 feat(hardware): the routed board, its drawings and the pod that no longer fits
    663 tracks, 172 vias, ZERO DRC errors and 17 connections still open, on the
    50 x 16 board with every passive on the back. The seven copper sheets, the
    assembly drawing, the 3D views and the pod's STLs were all regenerated from
    it.
    The pod now FAILS its own PD10 and PD17, and that is correct: it is 21.0 mm
    wide against the 20 mm target, because the board grew to 16 mm while the pod
    still stacks the cell UNDER it (floor 1.0 + cell 4.0 + air 0.5 + board 0.8 +
    ceiling 2.7 + lid 1.0). The decision of 2026-09-30 was to put the cell BESIDE
    the board so the device gets lower; the board was rebuilt for it and the pod
    was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
    [pmeter.kicad_pcb, pod-concha.stl, pod-tampa.stl]
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2026-09-30 feat(hardware): give the router a bare board - the pour comes after the track
    The owner's rule, and it is the right order: first the copper that carries
    signal, then the ground around it.
    KiCad exports each pour as (plane GND (polygon <layer> ...)), and there are
    three: In1.Cu, which is the real plane, and F.Cu and B.Cu, which are the
    faces Freerouting draws on. On those two the pour is only in the way - it is
    already there, covering everything, before a single track exists, and
    Freerouting's own v2.4.1 notes warn that routing over a copper plane produces
    clearance violations. It was drawing one of them that crashed its renderer.
    So the two routing-face pours leave the DSN, and fill_zones.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
    [pmeter.kicad_pcb]
2026-09-30 fix(hardware): the no-plane area forbids a GROUND via, not every via
    The rule was right and its scope was wrong, and it had been strangling the
    nPM1100 for the whole project.
    SEM_PLANO_BUCK_SW exists so that no GROUND via sits under the switching node
    - a ground via there brings the plane straight back under the noisiest point
    on the board, which is what the AEM10900 datasheet asks to remove. The board
    file says as much: that keepout is (tracks allowed) (vias allowed) and only
    (copperpour not_allowed).
    route.base() was blocking EVERY via of EVERY net inside it. And U101 sits
    entirely inside that area - it runs from (4.4; 5.4) to (9.4; 9.7) and the
    nPM1100 is at (8.3; 7.3) - so not one of i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
    [_inc.dsn, pmeter.kicad_pcb]
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2026-10-01 fix(hardware): three faults that made our own passes undo the router's work
    Each one was found by measuring the board between the stages instead of only
    at the end, and each one had been quietly costing connections.
    The 45-degree rewrite was applied to EVERY track, including the router's.
    stitch_gnd draws its ground stubs at whatever angle the grid leaves, and
    rewrote them into an L of 45 degrees plus a straight run - correct for its
    own stubs, and catastrophic for Freerouting's, which produces segments off
    45 degrees, as it warns itself ("Invalid traces after autoroute: N traces
    not 45 degree"). Each of those became an L that went somewhere else. The
    board left Freerouting with ZERO DRC er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
    [pmeter.kicad_pcb]
2026-10-01 feat(hardware): one connection open, and the ground stitched before the router
    From 21 connections without copper yesterday to ONE, with zero DRC errors,
    and the thing that did it was the owner's instruction: close them one at a
    time instead of running everything at once and throwing the result away when
    it got worse.
    The order was wrong. The ground stitching ran AFTER the router, and on a
    board that is already full a via has nowhere to land: of the 112 items it
    placed, 105 were too close to the router's copper and the cleanup removed
    them - which also removed the edge stitching, and GN2 said so ("only 1
    ground via within 3 mm of the edge: there is no stitching"). A plane with no
    stitching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
    [_antes_4.kicad_pcb, _antes_5.kicad_pcb, _antes_6.kicad_pcb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]
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2026-10-01 feat(hardware): the board is routed - 0 DRC errors, 0 connections open
    838 tracks, 221 vias, zero DRC errors and ZERO unconnected items, against 21
    open yesterday. The 52 violations left are the known warnings: 44 library
    footprint mismatches, because this project's footprints are generated, 7
    library issues and one silkscreen at the edge.
    RT1 passes for the first time. GN1 says all 49 surface ground pads are
    connected, 42 of them by a via of their own to the inner plane; GN2 counts 73
    vias along the edge with a largest gap of 3.0 mm. The board's dry run goes
    from 14 rules met and 6 violated to 16 and 4.
    What closed it was the ORDER, not the tool, and it was the owner's call: one
    at a time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
    [pmeter.kicad_pcb]
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2026-10-01 fix(hardware): measure the pod's drawn solid, and close the seven blockers
    Ten reviewers measured the pod on 2026-10-01 and found seven interferences
    that stopped it closing. In the same commit the dry run reported 18 of 20
    rules met. One cause: the drawing is a triangle soup, Malha could not
    subtract and could not be asked "is this point inside?", so seven rules read
    the CONSTANT that should have produced the geometry. A rule like that passes
    whether the feature was drawn or not - PARAF_PESCOCO_D = 2.00 had been
    declared all along while the boss came out at full 3.40 through a 2.20 hole,
    and no rule saw it.
    Malha now records every primitive in the SAME call that emits the triangles,
    so the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
    [pod-concha.stl, pod-tampa.stl]
2026-10-01 fix(hardware): cut the LED's light hole round, as the drawing always said
    The hole was a 2.5 x 2.5 square - 6.25 mm2 - where the PDF drew and the text
    announced a circle of 2.5, which is 4.91: 27 % more area for the clear resin
    to fill, with the drawing saying one thing and the STL being another. The
    volume estimate used the square and the PDF used the circle.
    placa_com_furos only knows rectangles, so the plate takes a 2.6 square and a
    ring between that square and a 16-sided polygon brings the circle back. PD9
    measures the area IN THE SOLID and fails above 5 % over a perfect circle;
    with the hole square again it reports 6.25 against 4.91.
    The first try made the square's side equal to the d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
    [pod-tampa.stl]
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2026-10-01 feat(hardware): derive the pod's wall from its seal, and the width fits the arm
    The wall was 2.0 mm because the O-ring groove needs 1.05 plus 0.5 of land
    each side. But wall and groove were written as two loose numbers and nobody
    had tied one to the other, so the wall stayed at 2.0 after the cord could
    already be smaller. PAREDE is now JUNTA_SULCO_L + 2 * JUNTA_TERRA, and with a
    0.60 cord instead of 0.80 it comes to 1.50 and the pod to 20.00 wide against
    the 20.0 of the class's crank-arm face. PD17 passes for the first time; the
    pod is 73.5 x 20.0 x 7.2 and 13.4 g. The 0.60 cord is a purchase requirement,
    and if it cannot be found the fallback is a face gasket with a 1.2 wall.
    PD13 now meas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
    [pod-concha.stl, pod-tampa.stl]
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
